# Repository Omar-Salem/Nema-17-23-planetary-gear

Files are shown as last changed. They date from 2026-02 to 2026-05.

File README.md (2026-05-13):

# Nema-17/23-planetary-gear

A fully parametric planetary gearbox designed for NEMA 17/23 motors.

Gear ratio, backlash, and geometry can be adjusted through parameters.

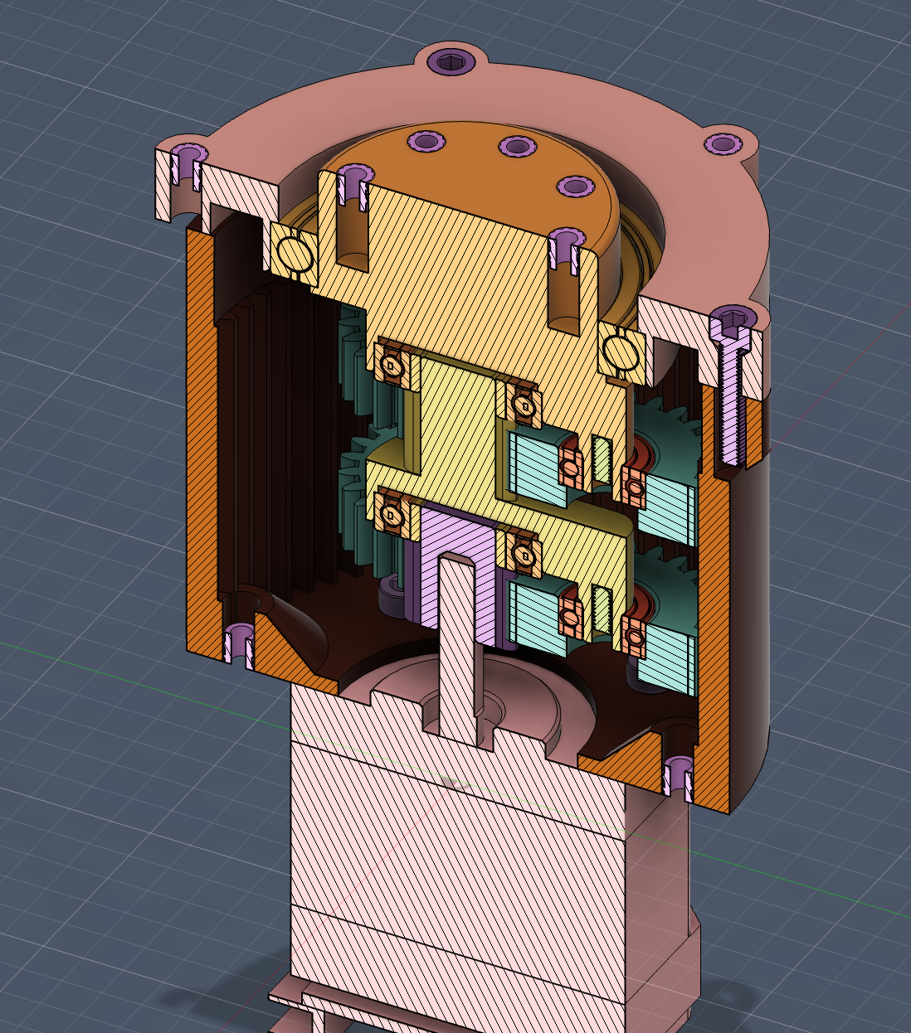
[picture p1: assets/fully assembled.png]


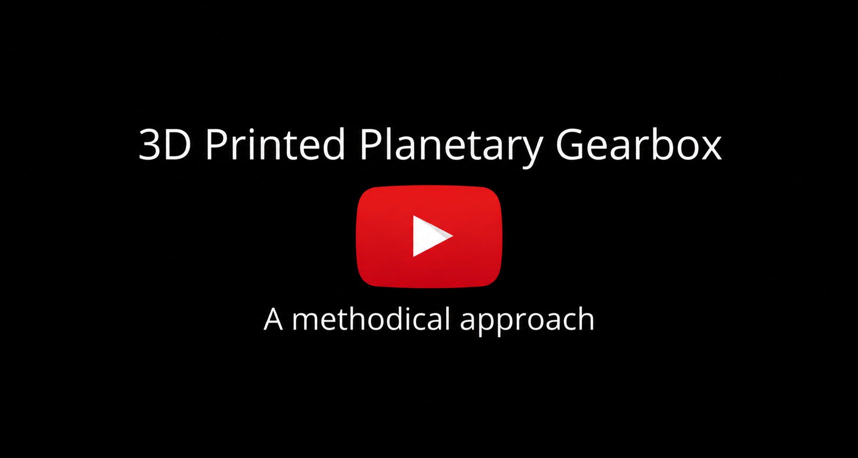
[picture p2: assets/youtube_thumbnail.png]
Watch the video (https://www.youtube.com/watch?v=zlH5y5JG1OU)


### Software Requirements 
[Fusion 360 (free to download)](https://www.autodesk.com/campaigns/fusion-360/download)

[Fusion 360 Helical Gear Plus plugin](https://apps.autodesk.com/FUSION/en/Detail/Index?id=1259509007239787473&appLang=en&os=Mac)

### Parts List
#### for Nema 17
* M3 heat inserts 
    * (L5 $\times$ 4.2mm OD) $\times$ 15
* M3 hex bolts
    * 91290A120 (16mm)  $\times$ 3
    * 91290A115 (10mm)  $\times$ 6
    * 91290A111 (6mm)  $\times$ 4
* Deep groove ball bearings
    * 4668K269 (35mm $\times$ 47mm $\times$ 7mm) $\times$ 1
    * 2349K726 (12mm $\times$ 21mm $\times$ 5mm) $\times$ 2
    * 4668K225 (5mm $\times$ 11mm $\times$ 5mm) $\times$ 6
#### for Nema 23
Substitute `91290A111` M3 hex bolts with `91290A221` M5

The above is for `gear_ratio` **6**, for different ratios you'll need different bearing sizes, refers to parameters in design files
### Design Notes

* Spur gears are used for simplicity and efficiency
* Sun gear is reused across configurations
* Three planets provide a balance between load sharing and complexity
* Geometry is driven by parameters (module, teeth count, bearing sizes)
* Single sided carrier

### Important Limitation
Parameters are not global across files.

If you change a parameter (e.g. `gear_ratio`, `helix_angle` etc..), you must update it in all other files.

This violates DRY principle, instead, global params should be used.

[Global Parameters in Fusion 360 | Explained in 5 minutes](https://www.youtube.com/watch?v=VsqRV7JvBKc)

### Workflow Overview
The gearbox is built in three stages:

* Generate base gears (sun, planet, ring)
* Modify components 
* Assemble stages 

### Generate Gears

Create a new project and import the .f3d files

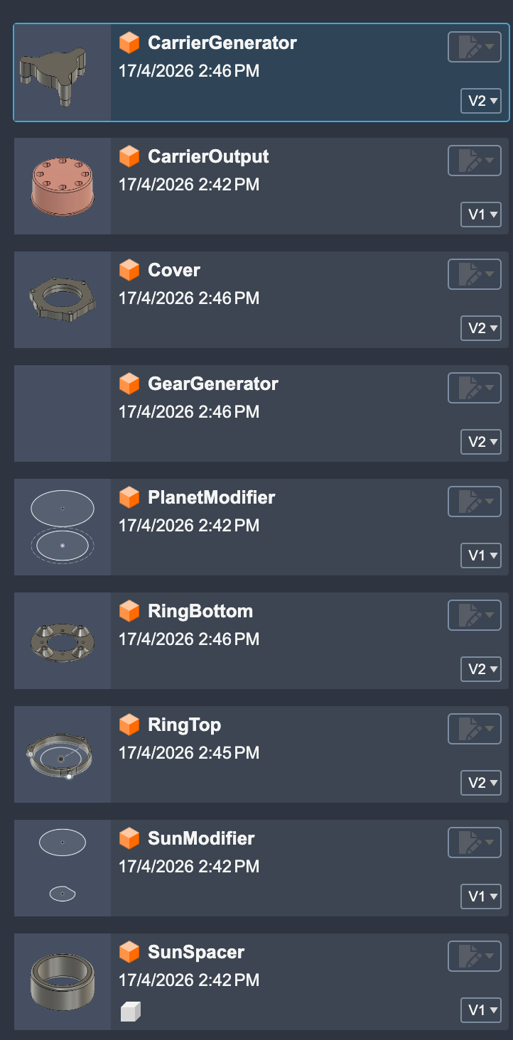
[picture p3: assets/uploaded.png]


Open `GearGenerator`

Start creating the sun gear, open `Helical Gear+`

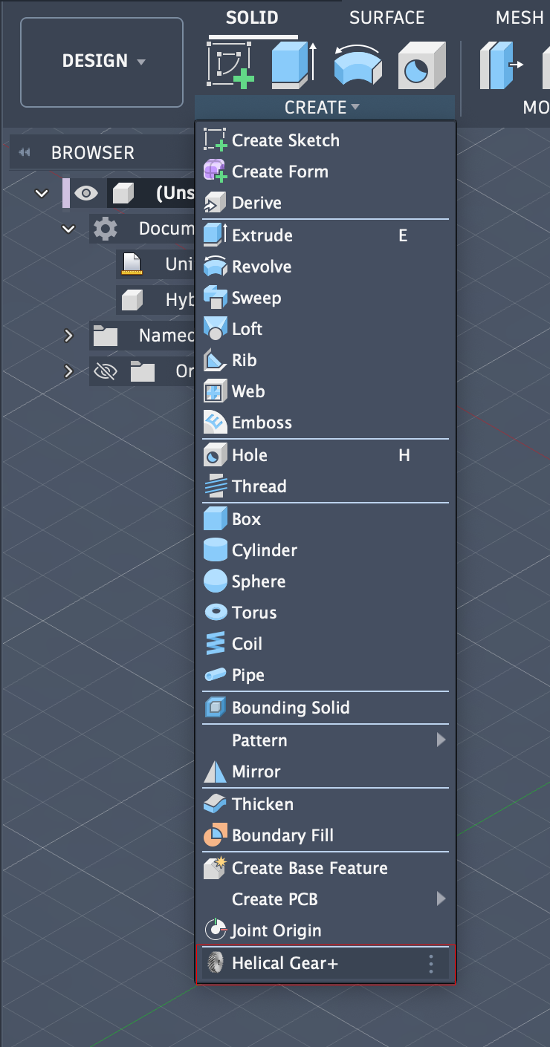
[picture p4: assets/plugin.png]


Fill the fields with the sun gear params

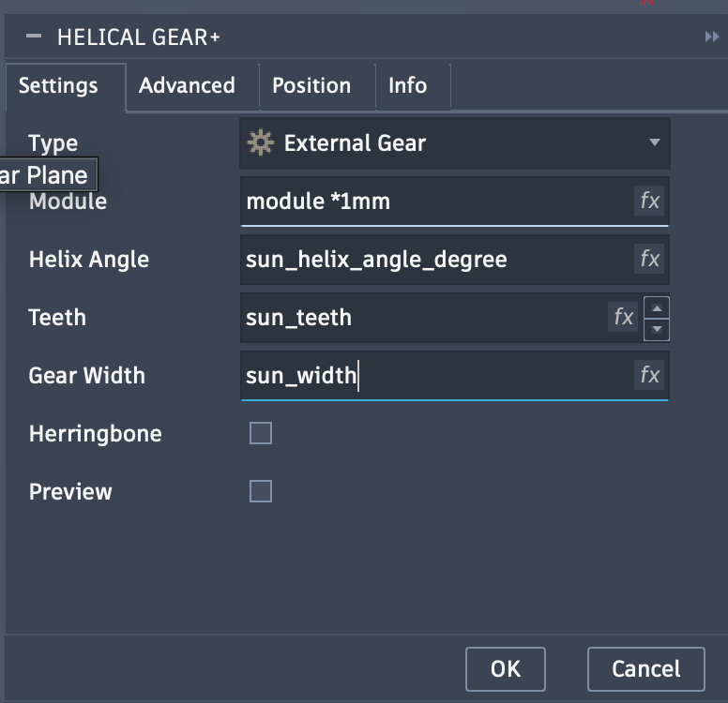
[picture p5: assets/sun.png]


(_Advanced config will be the same for planet and ring_)

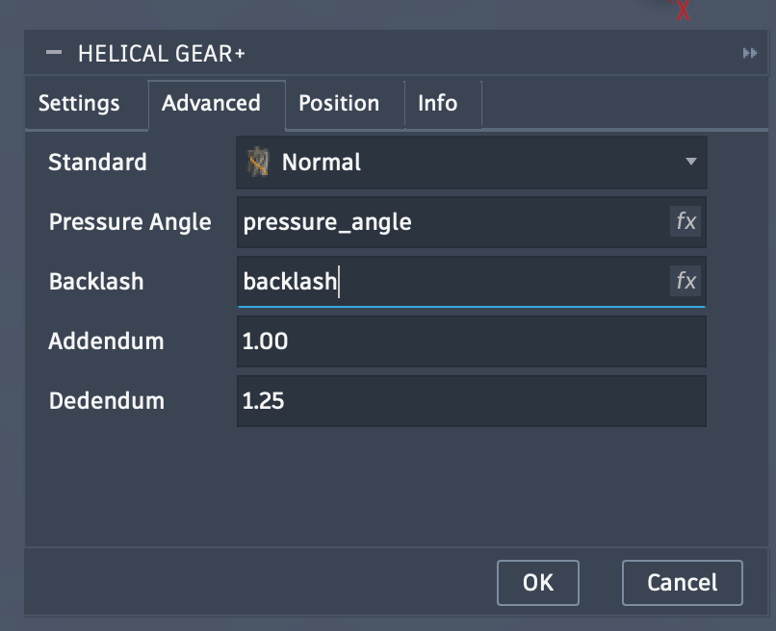
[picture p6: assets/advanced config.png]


In the same manner create the planet gear

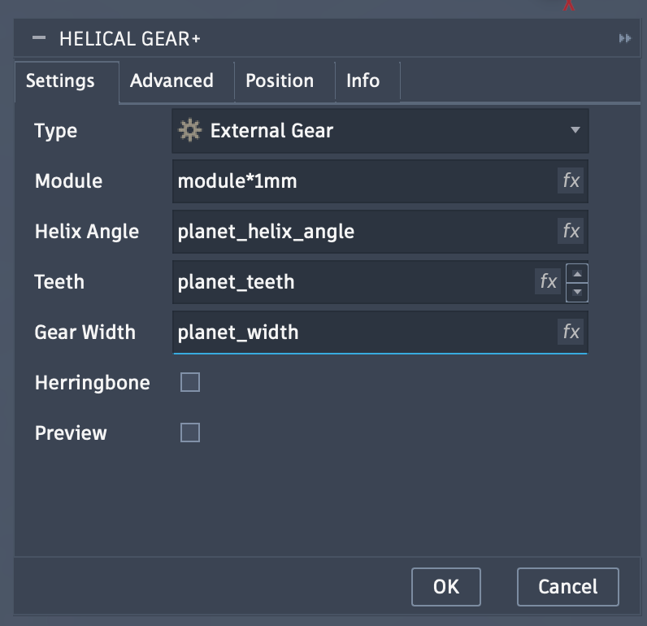
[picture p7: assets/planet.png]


And the ring gear, don't forget to change Type to `Internal Gear`

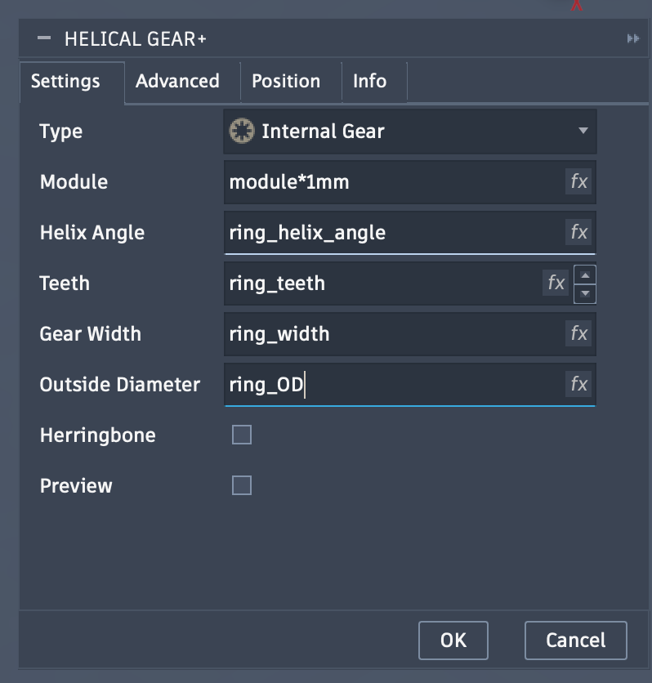
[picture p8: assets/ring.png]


You should end up with this

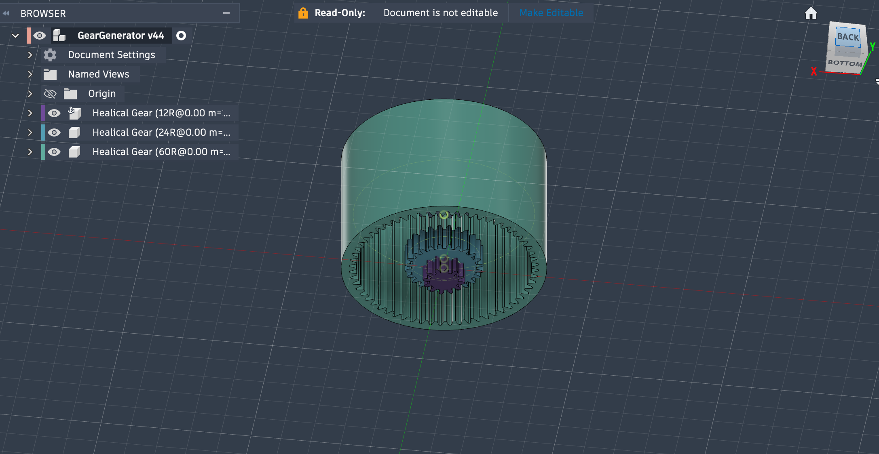
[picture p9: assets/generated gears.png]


Export ring gear as `Ring` to your project

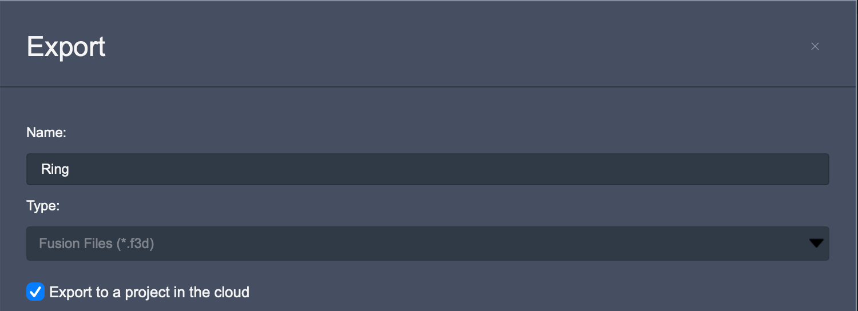
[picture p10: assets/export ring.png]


Export planet gear as `PlanetTemp` and sun gear as `SunTemp`

Close current design without saving

### Modify Components

Open `SunModifier`

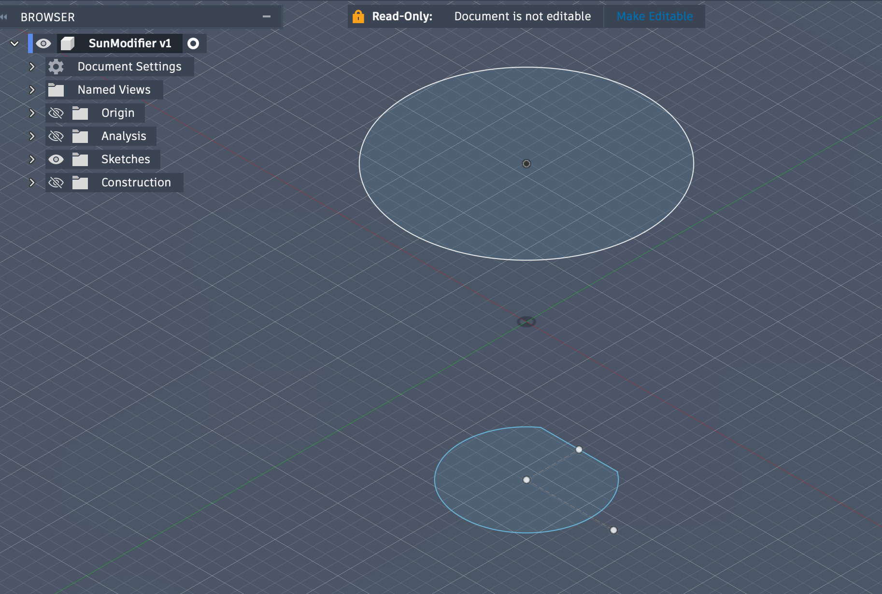
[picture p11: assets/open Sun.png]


Insert the `SunTemp` component

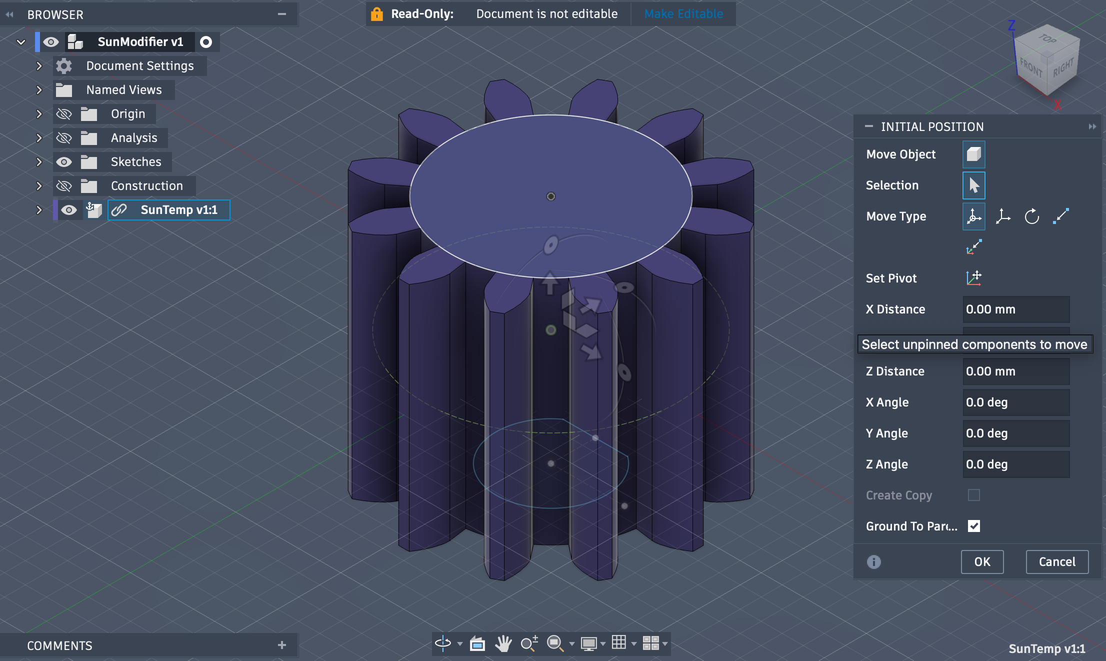
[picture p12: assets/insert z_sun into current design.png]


Break the link

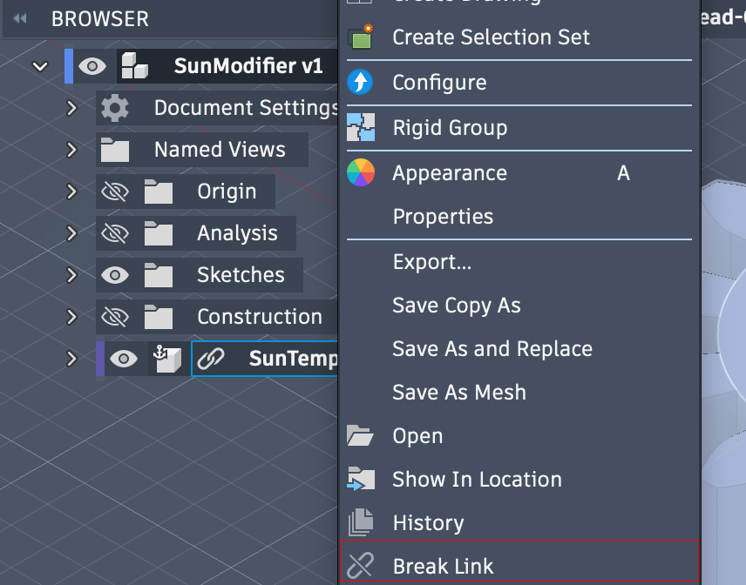
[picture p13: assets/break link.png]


Extrude and fillet the bearing mount, make sure operation for extrude is `Join`

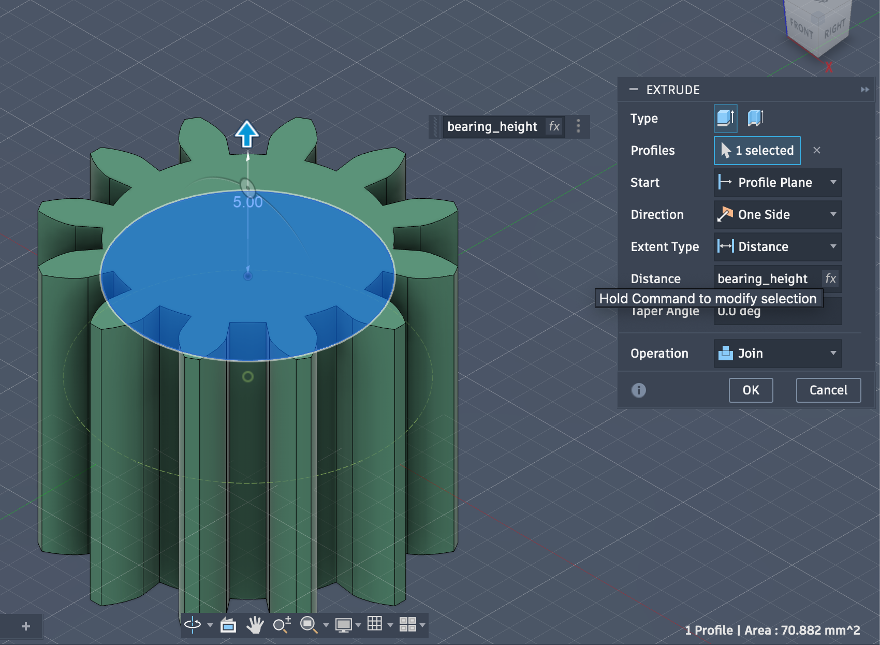
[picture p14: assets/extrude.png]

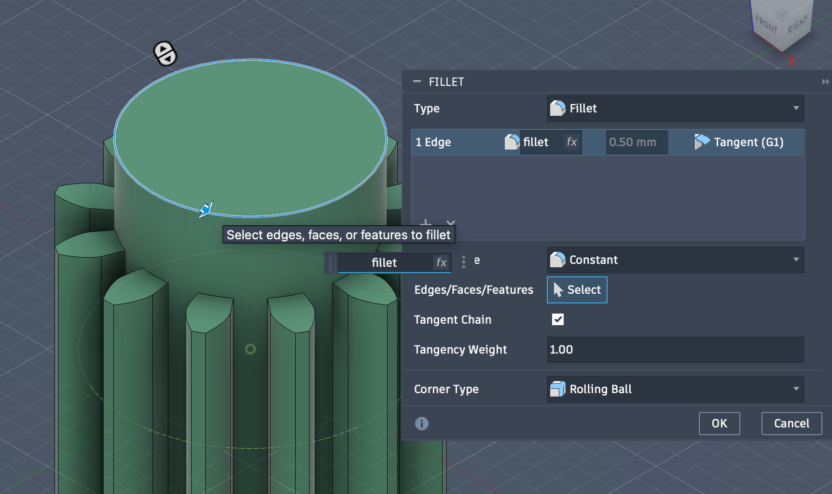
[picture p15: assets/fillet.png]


Export component as `Sun` to your project

Cut and fillet motor shaft

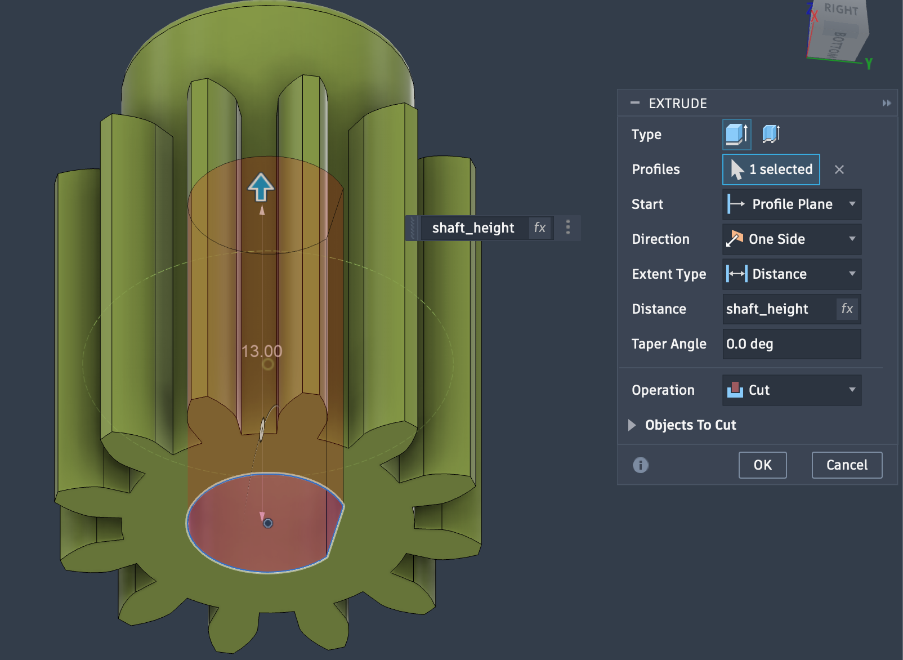
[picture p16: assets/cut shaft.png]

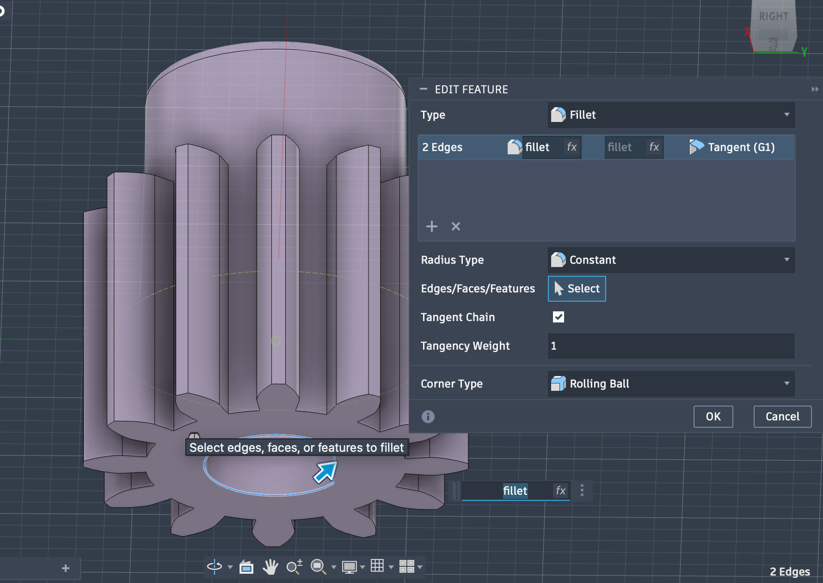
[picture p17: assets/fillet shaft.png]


Chamfer from the inside

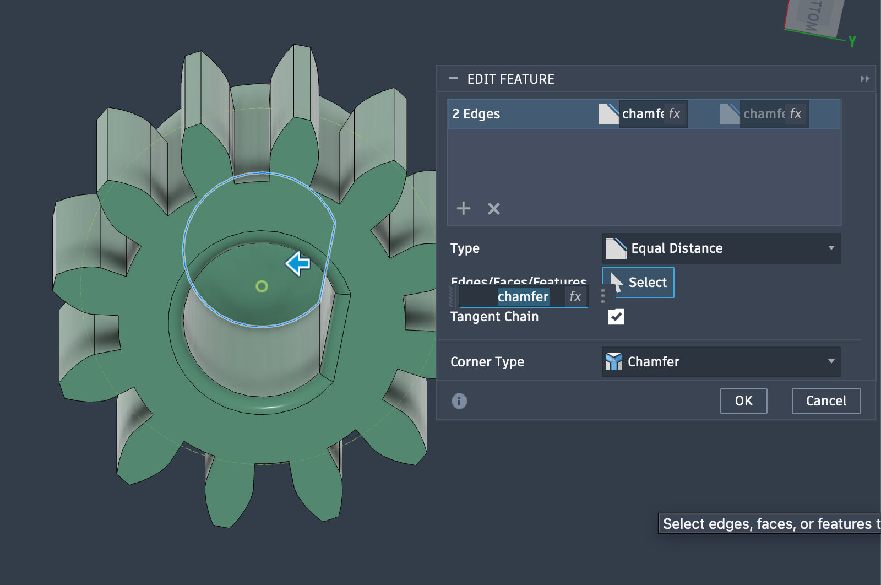
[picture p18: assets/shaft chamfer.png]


Should end up with this

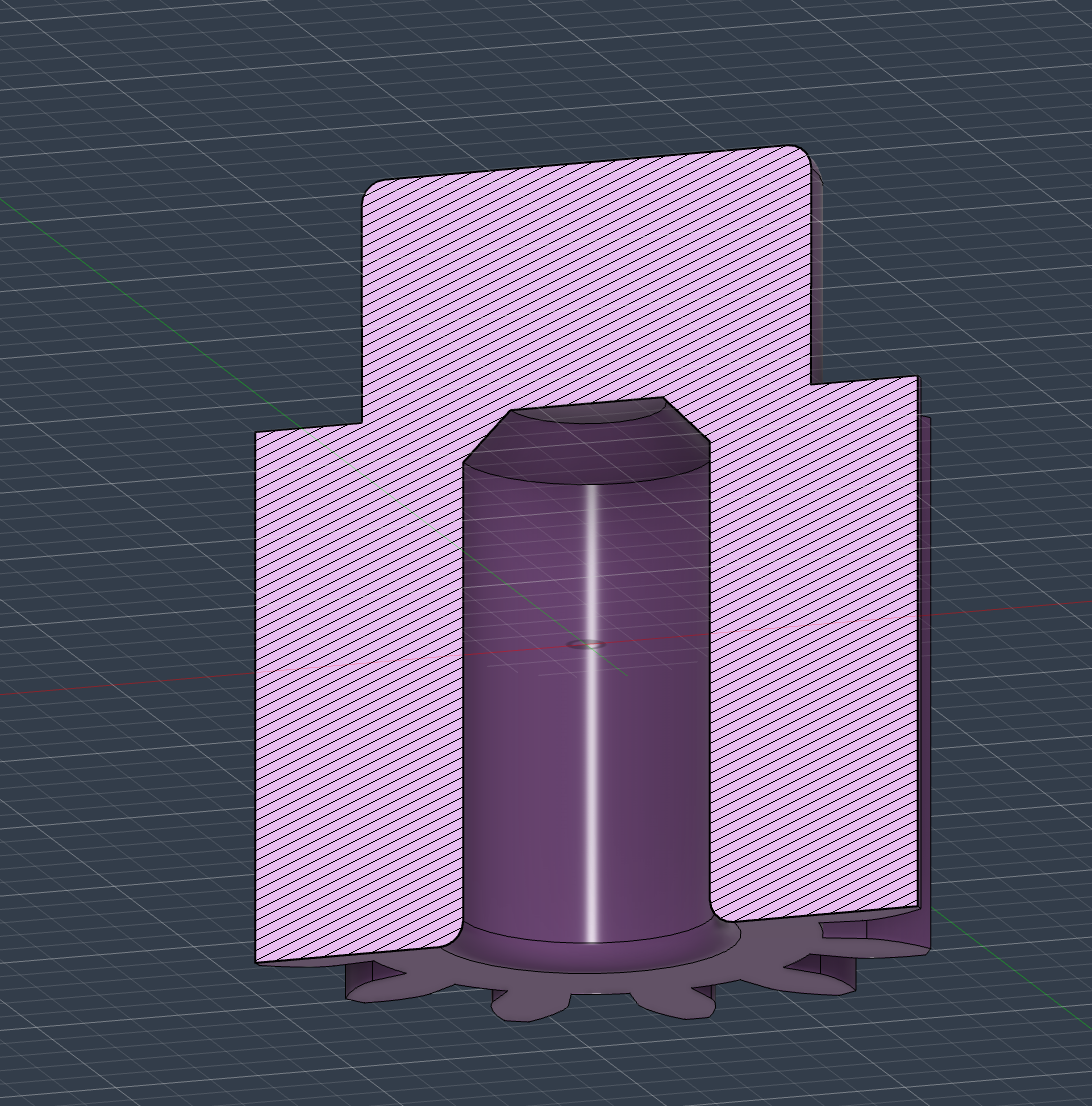
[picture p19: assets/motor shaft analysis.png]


Export component to project as `MotorInput`

Close current design without saving

_If you create another gearbox with a different gear ratio, `Sun` and `MotorInput` will stay the same, no need to regenerate them_

Move `SunTemp` to trash

---
In the same manner, open `PlanetModifier` and insert `PlanetTemp`

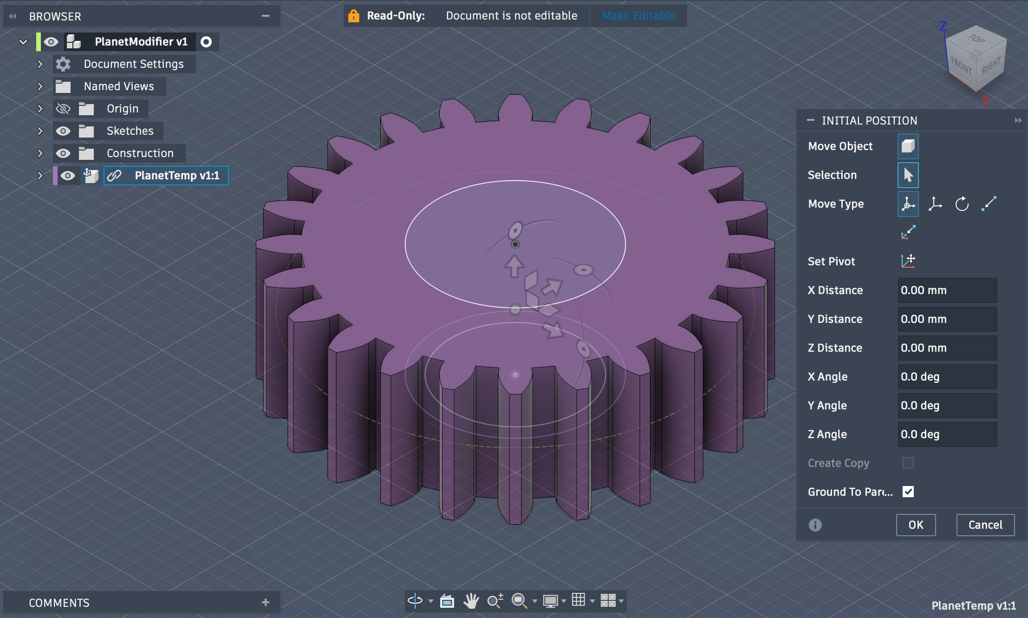
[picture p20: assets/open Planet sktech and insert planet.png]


Break link

Cut hole for bearing

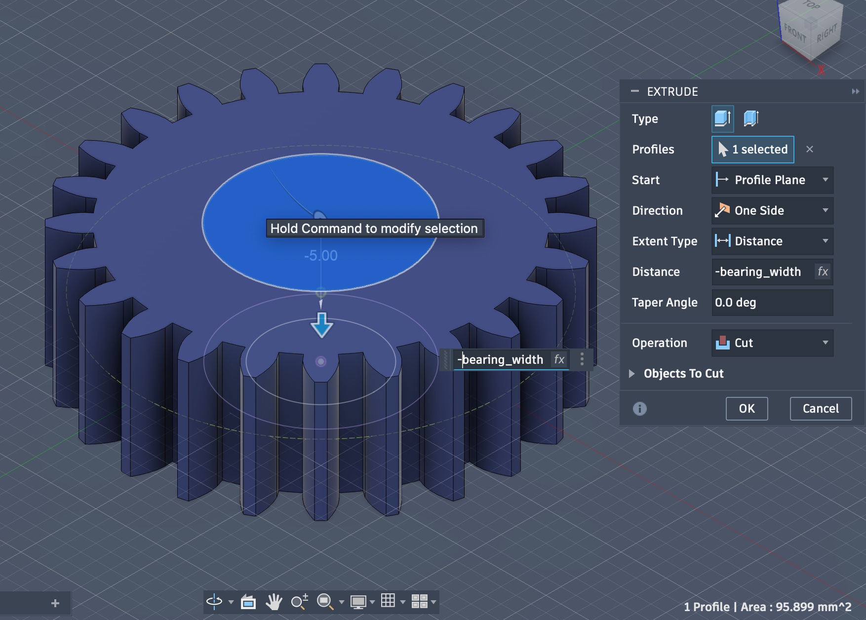
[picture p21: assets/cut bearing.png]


Fillet

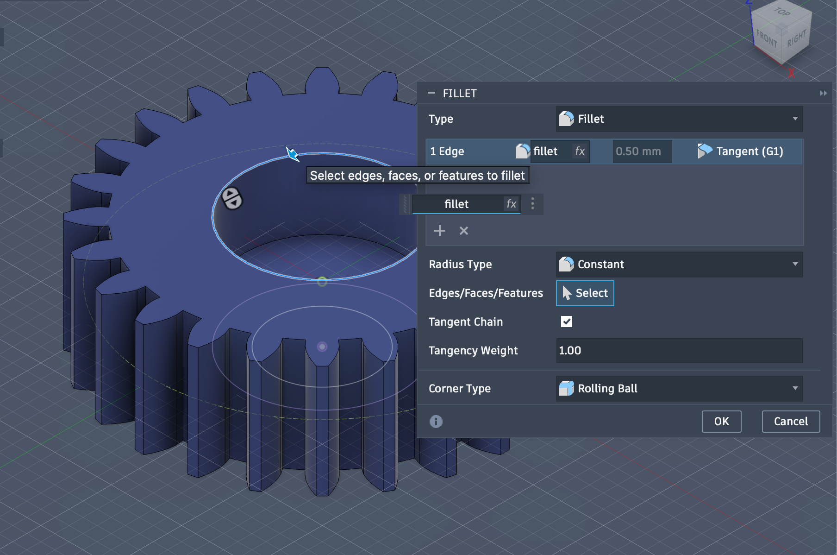
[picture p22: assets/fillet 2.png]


Cut hole for bearing lip

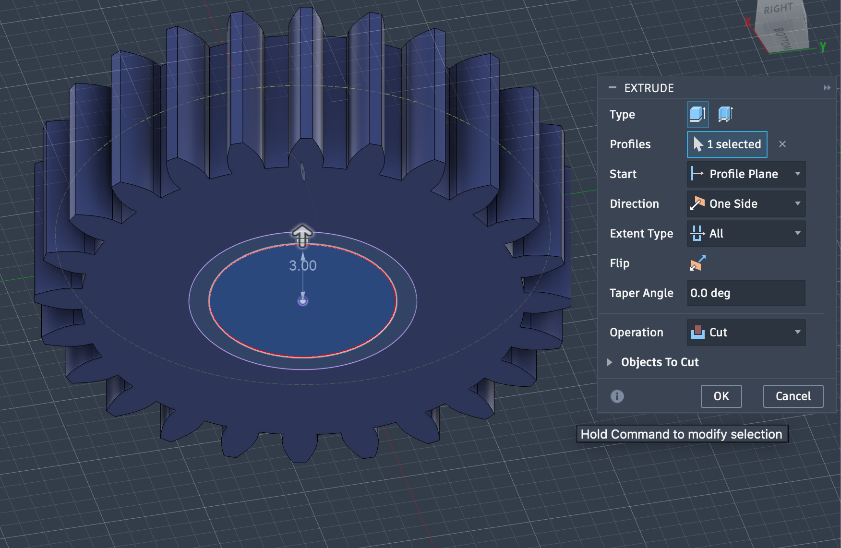
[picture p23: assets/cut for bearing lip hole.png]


Should end up with this

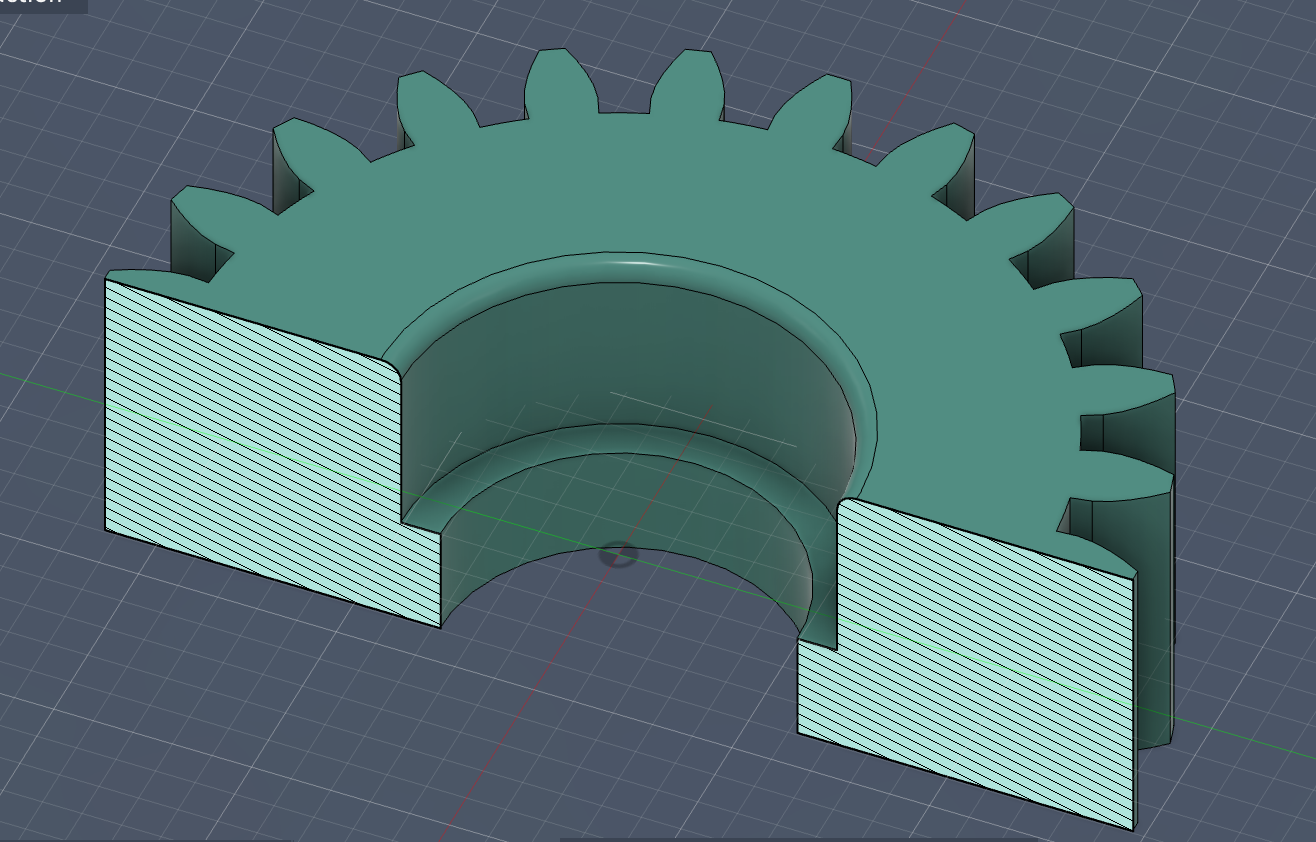
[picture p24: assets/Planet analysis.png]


Export to project as `Planet`

Close current design without saving

Move `PlanetTemp` to trash

We now have all the components, time to combine them

### Assemble Components

Open `Ring`, import `RingBottom` and `RingTop`

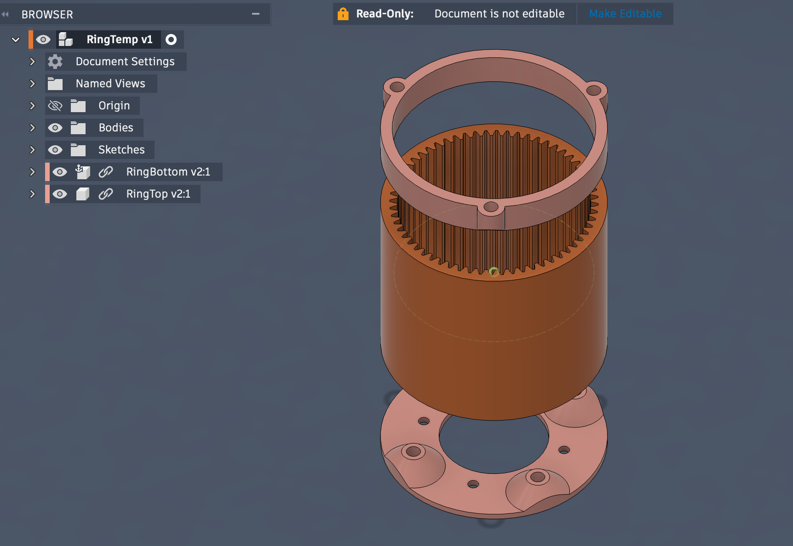
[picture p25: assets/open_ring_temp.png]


Join `RingBottom` and `Ring` at their bottoms

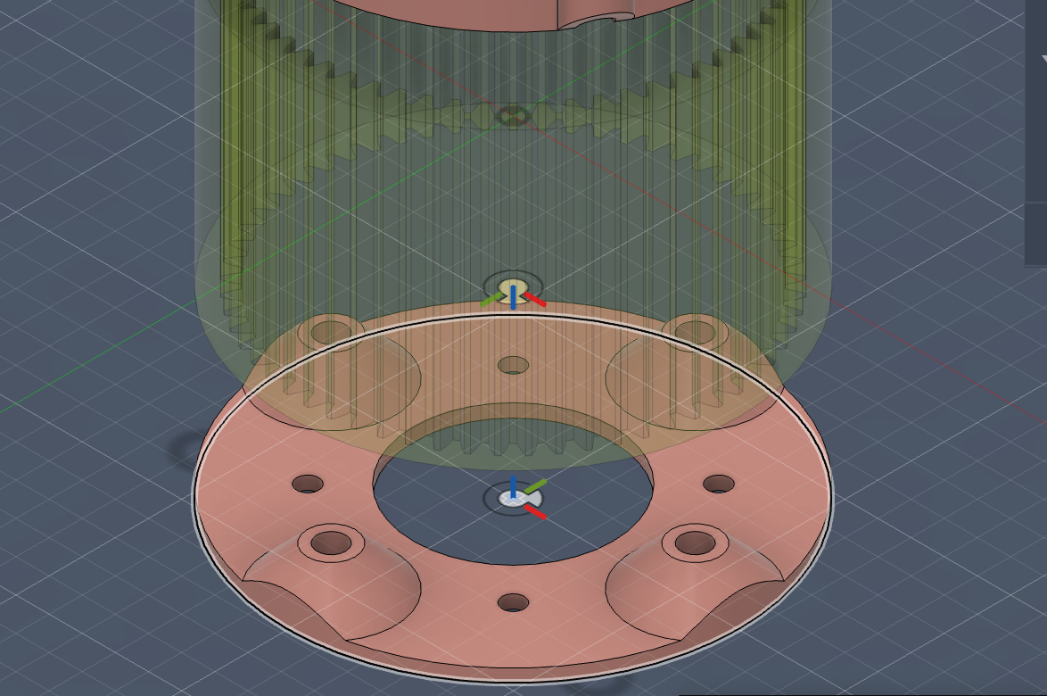
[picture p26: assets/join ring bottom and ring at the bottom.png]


Join `Ring` and `RingTop` at their tops

Should end up with this

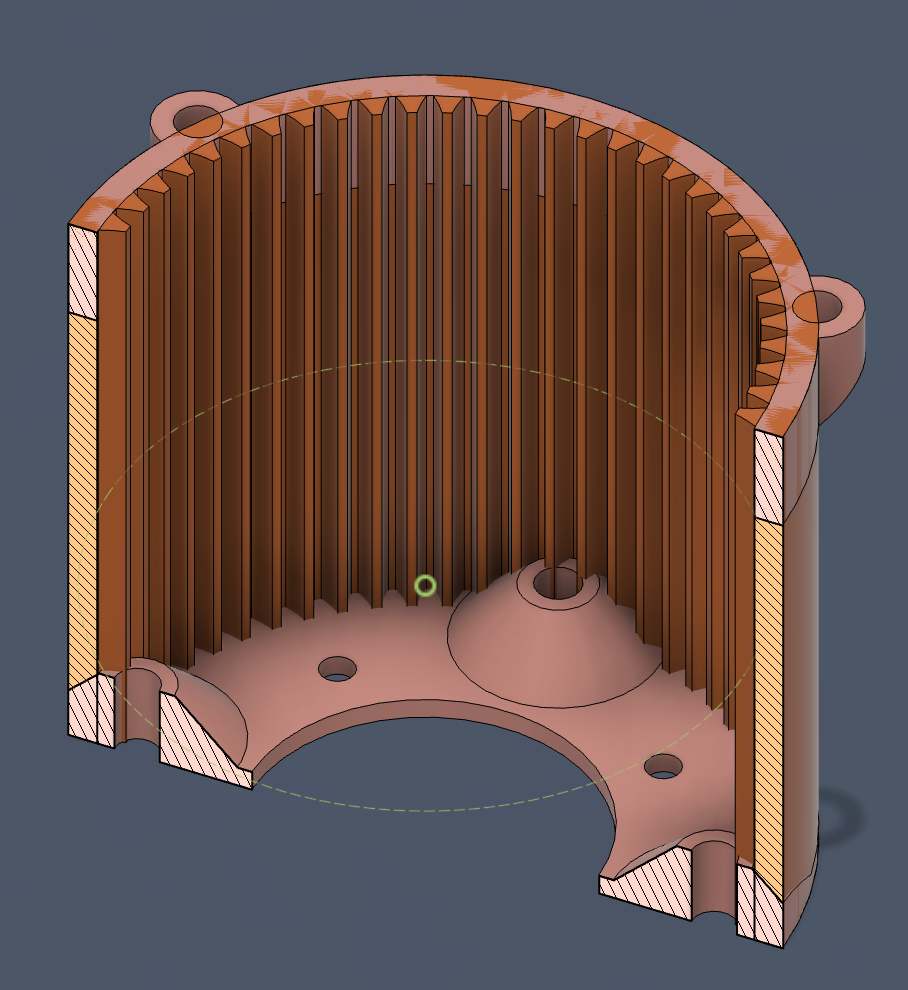
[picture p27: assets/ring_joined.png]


Combine all of them

Select and cut the 3 screw mounts

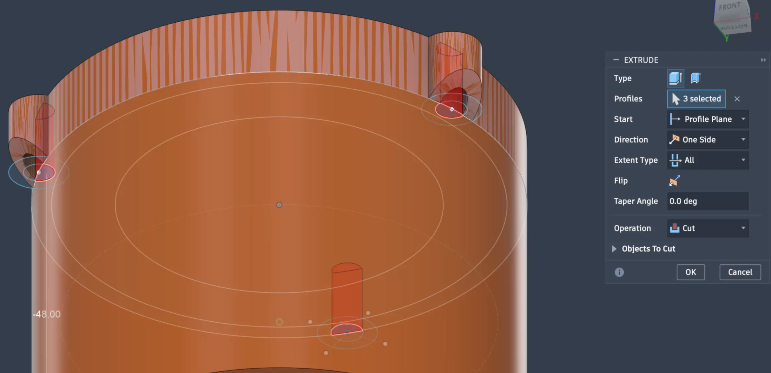
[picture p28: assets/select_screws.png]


Remove `RingBottom` and `RingTop`

Save

---

Open `CarrierGenerator`

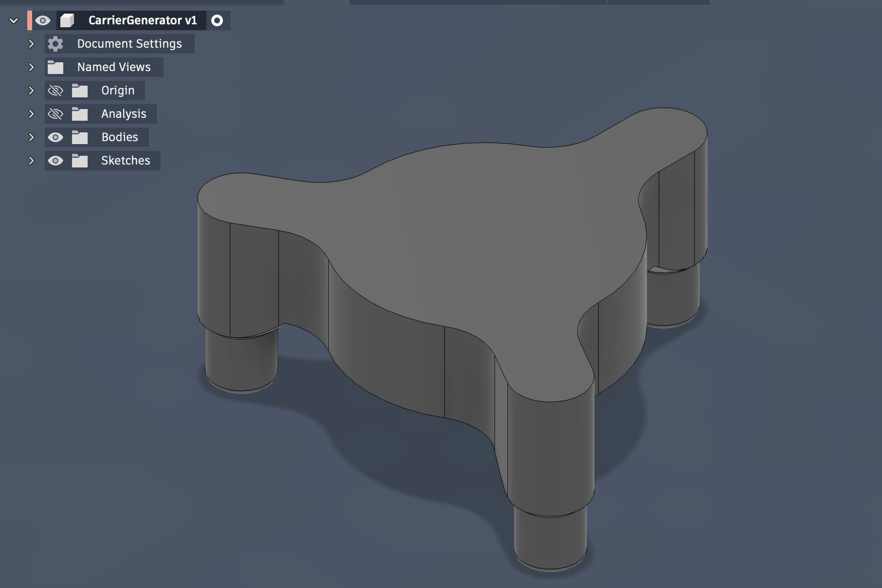
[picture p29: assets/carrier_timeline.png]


Insert `Sun`

Join `Sun`'s bottom with `Carrier`'s top at their centers

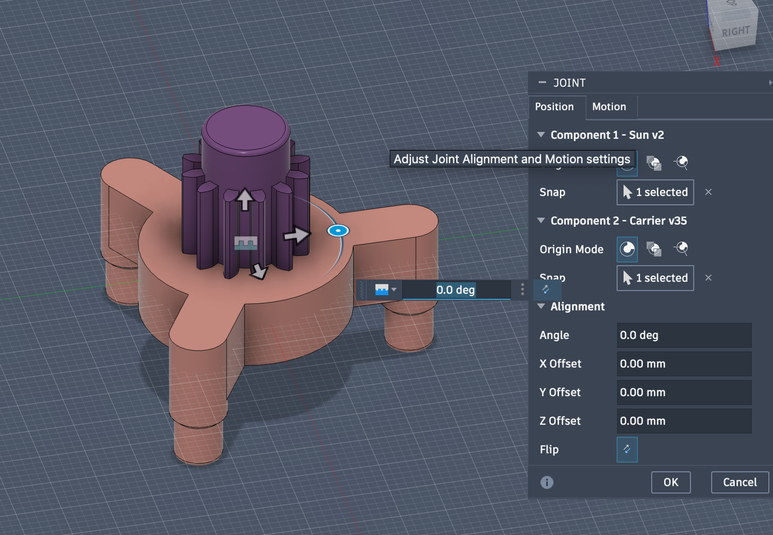
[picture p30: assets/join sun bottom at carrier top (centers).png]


Should end up with this

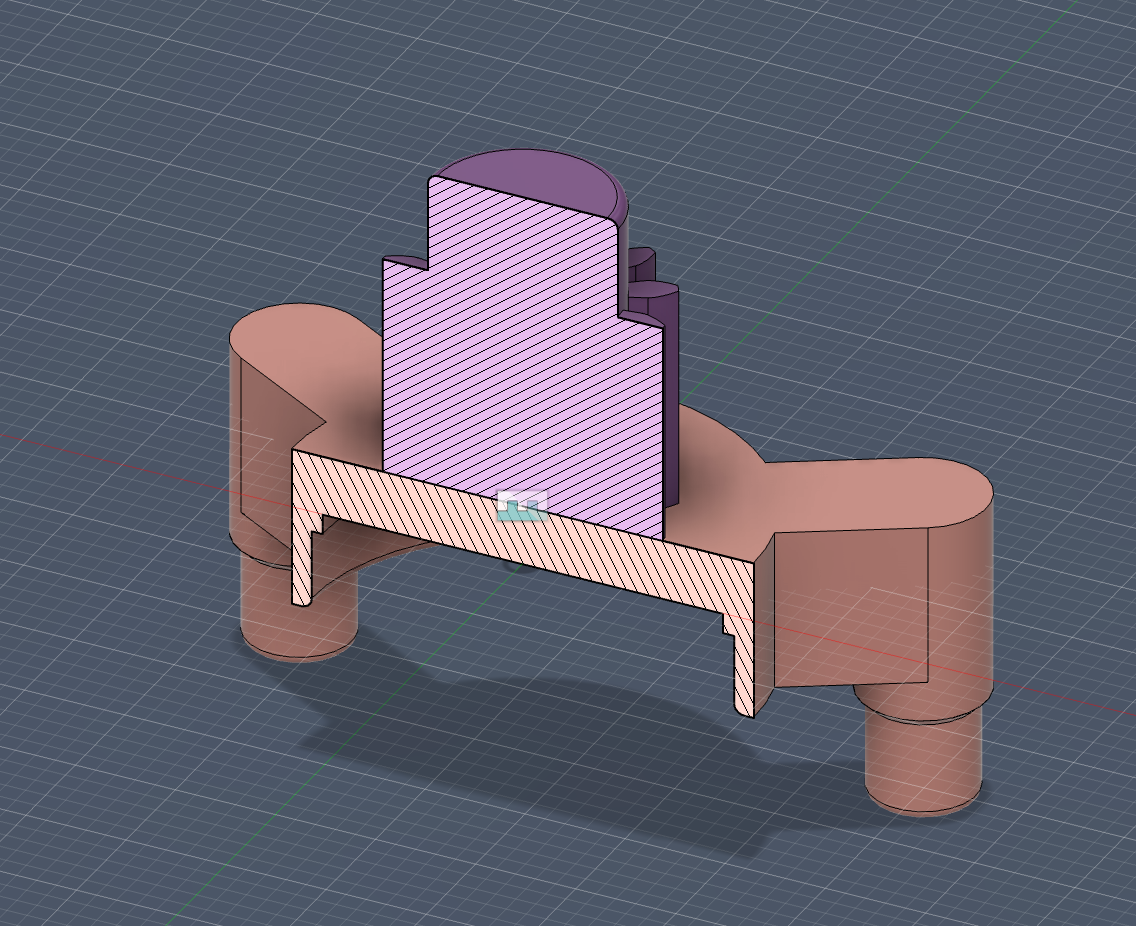
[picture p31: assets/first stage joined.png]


Combine all of them as new component

Export it to project as `FirstStage`

Close current design without saving

---

Open `CarrierGenerator` again

Insert `CarrierOutput`

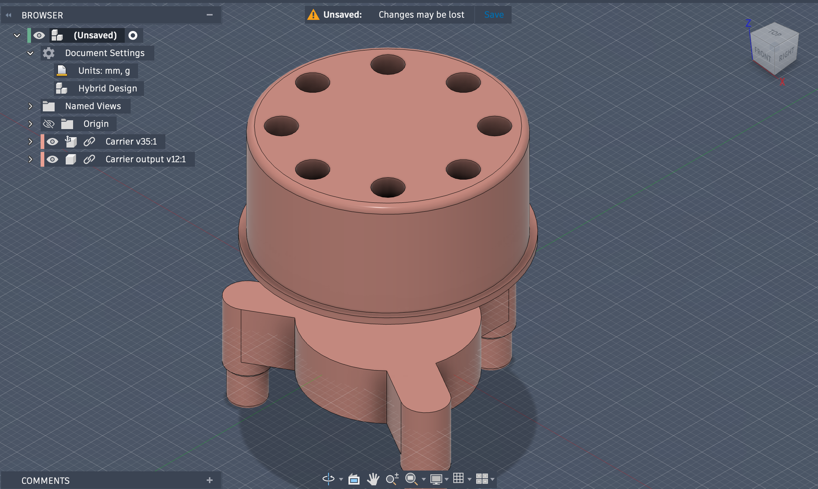
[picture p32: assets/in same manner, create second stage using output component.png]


Join `CarrierOutput` bottom at `CarrierGenerator`'s top at their centers

Should end up with this

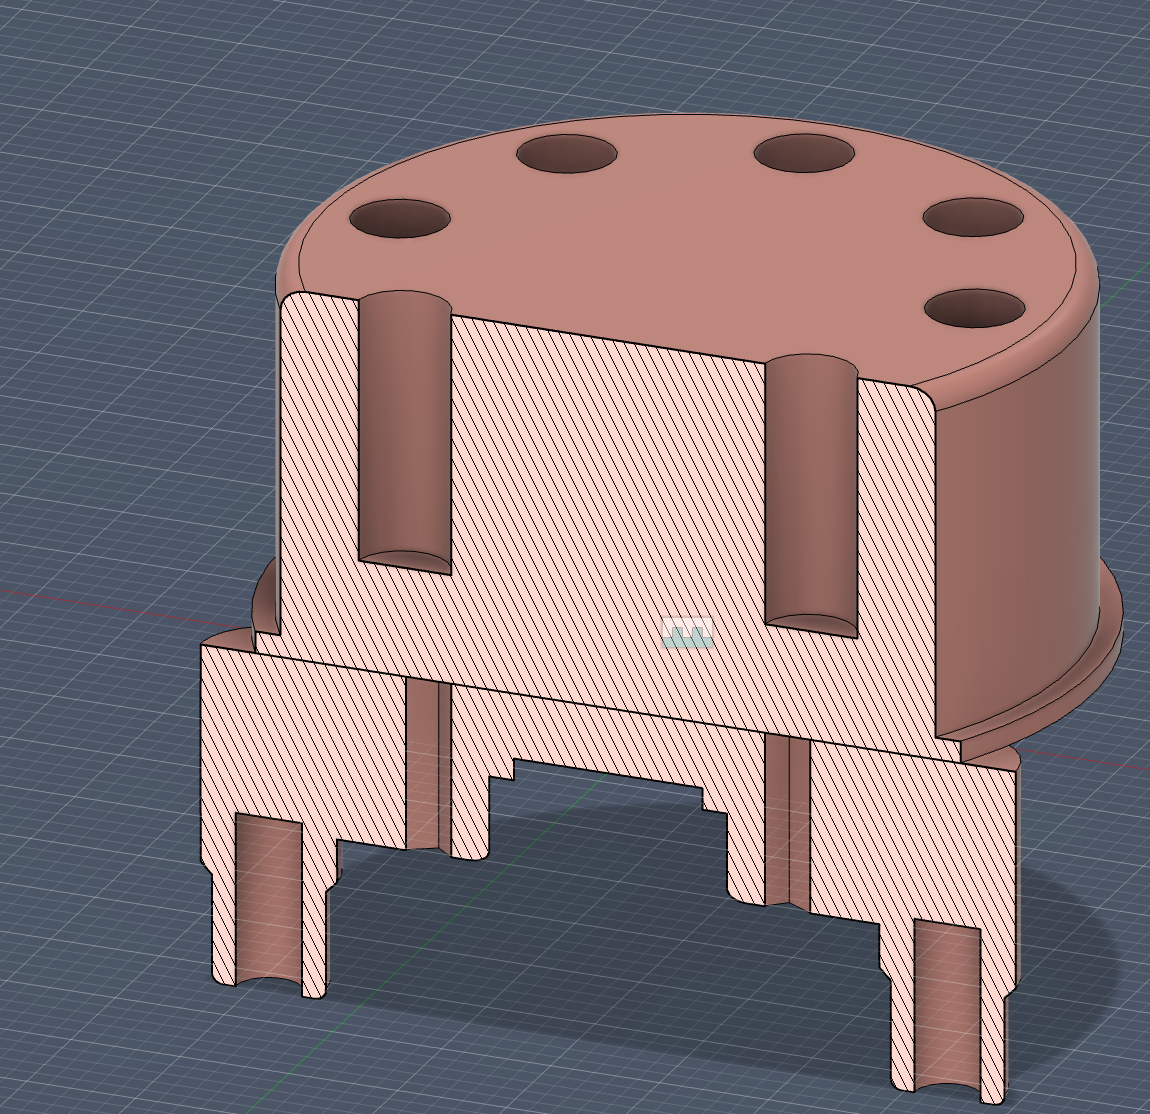
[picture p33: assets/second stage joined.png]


Combine all as new component, export it to project as `SecondStage`

### Export for Printing

* Cover
* FirstStage
* SecondStage
* Ring
* Planet
* MotorInput
* SunSpacer

❗ Make sure you print `SecondStage` at 45&deg; with 100% infill as it takes the most stress

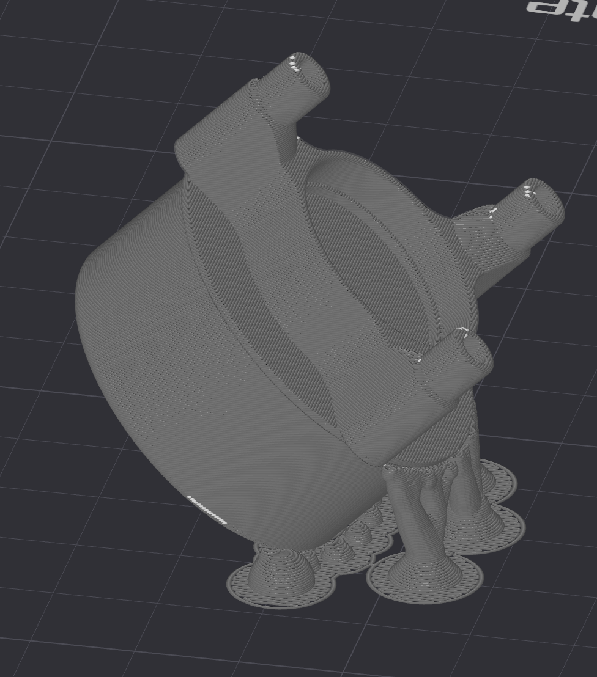
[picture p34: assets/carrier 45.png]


[The Correct Orientation to Print Boxes](https://www.youtube.com/watch?v=8NKVNwVaZU0)

[Autodesk Fusion: Make supports like Slant 3D](https://www.youtube.com/watch?v=sn2u949g7dM)

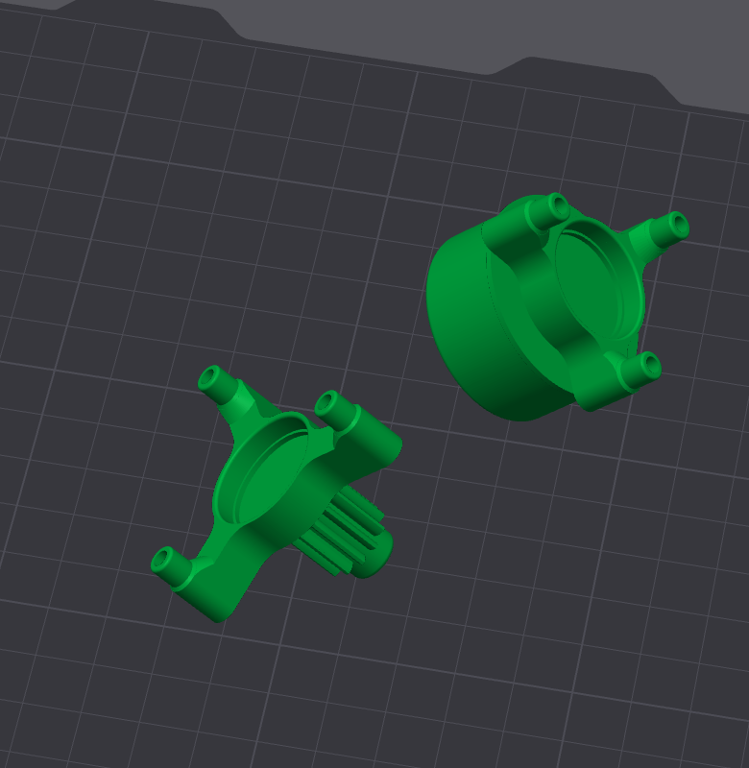
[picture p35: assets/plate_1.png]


6 `Planet`s

2 `SunSpacer`s (_1 per stage_)

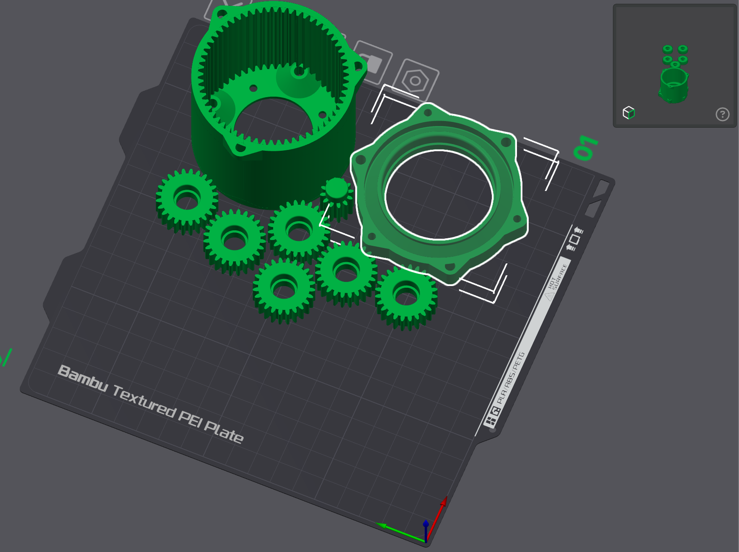
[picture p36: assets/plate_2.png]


### Assembly
1. Press the heat sinks into the ring.

1. Secure the sun gear onto the motor shaft. 

1. Bolt the ring to the motor using four 6mm M3 bolts. 

1. Seat the first 12mm bearing into the first stage, followed by the sun top to lock the sun in place. 

1. Install the three 5mm bearings onto the pins, mount the planet gears, and slide the first stage into position. 

1. Repeat these steps for the second stage, adding the three 10mm M3 bolt pin supports. 

1. Fit the 35mm bearing onto the output shaft.

1. Attach the cover with three 16mm M3 bolts.

1. Press the remaining heat sinks into the cover and output shaft.
 
 _Bearing sizes will change depending on gear ratio_

https://github.com/user-attachments/assets/527c2508-7acf-4f8b-a0d8-41f765740e9c

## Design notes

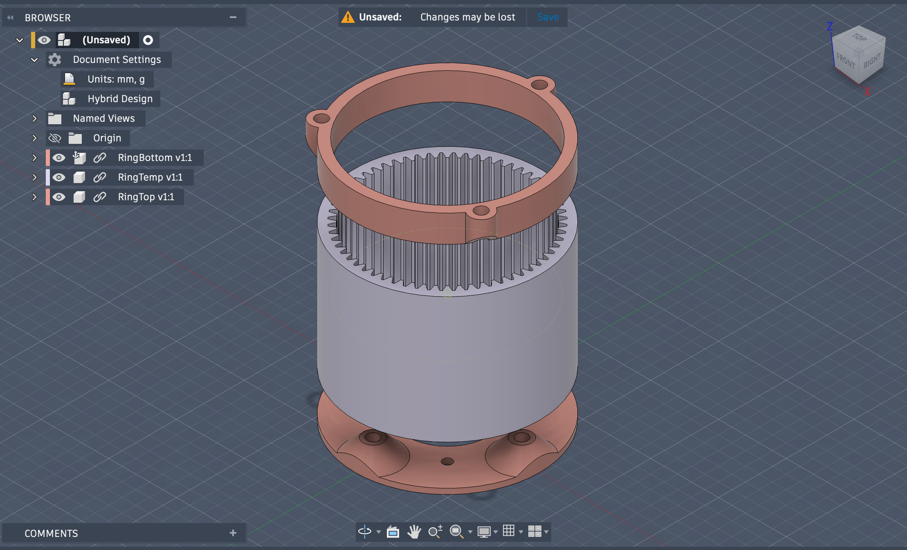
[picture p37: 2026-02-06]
assets/new hybrid design, insert ring,ring top and ring bottom.png

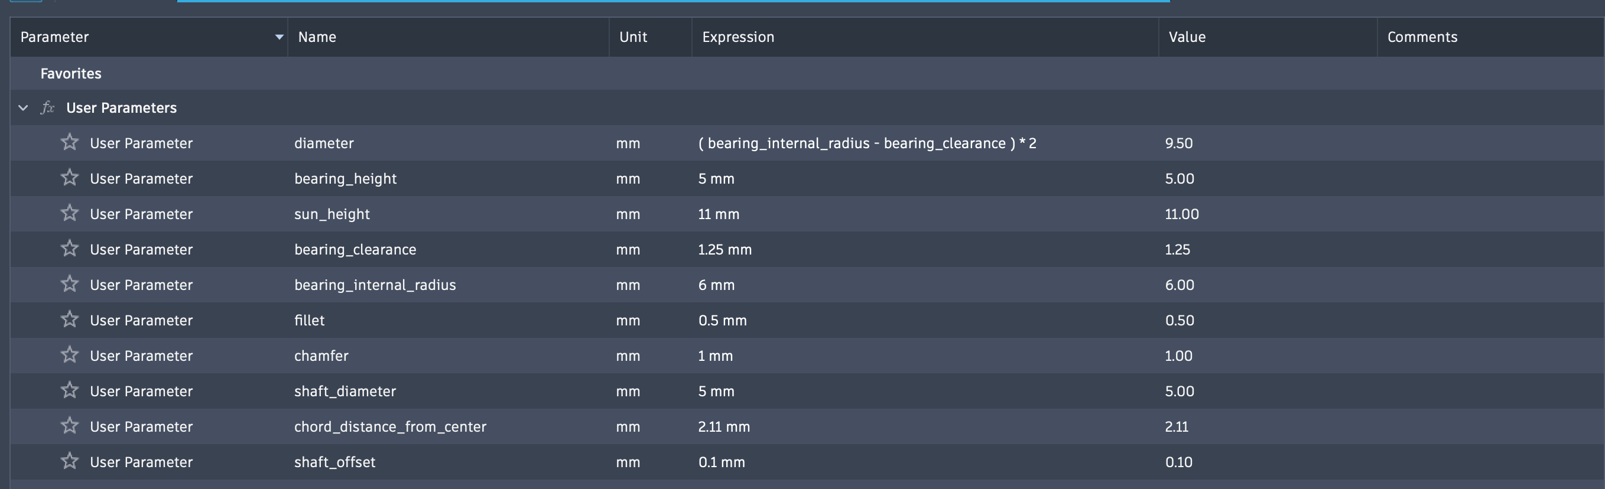
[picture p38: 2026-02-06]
assets/sun params.png

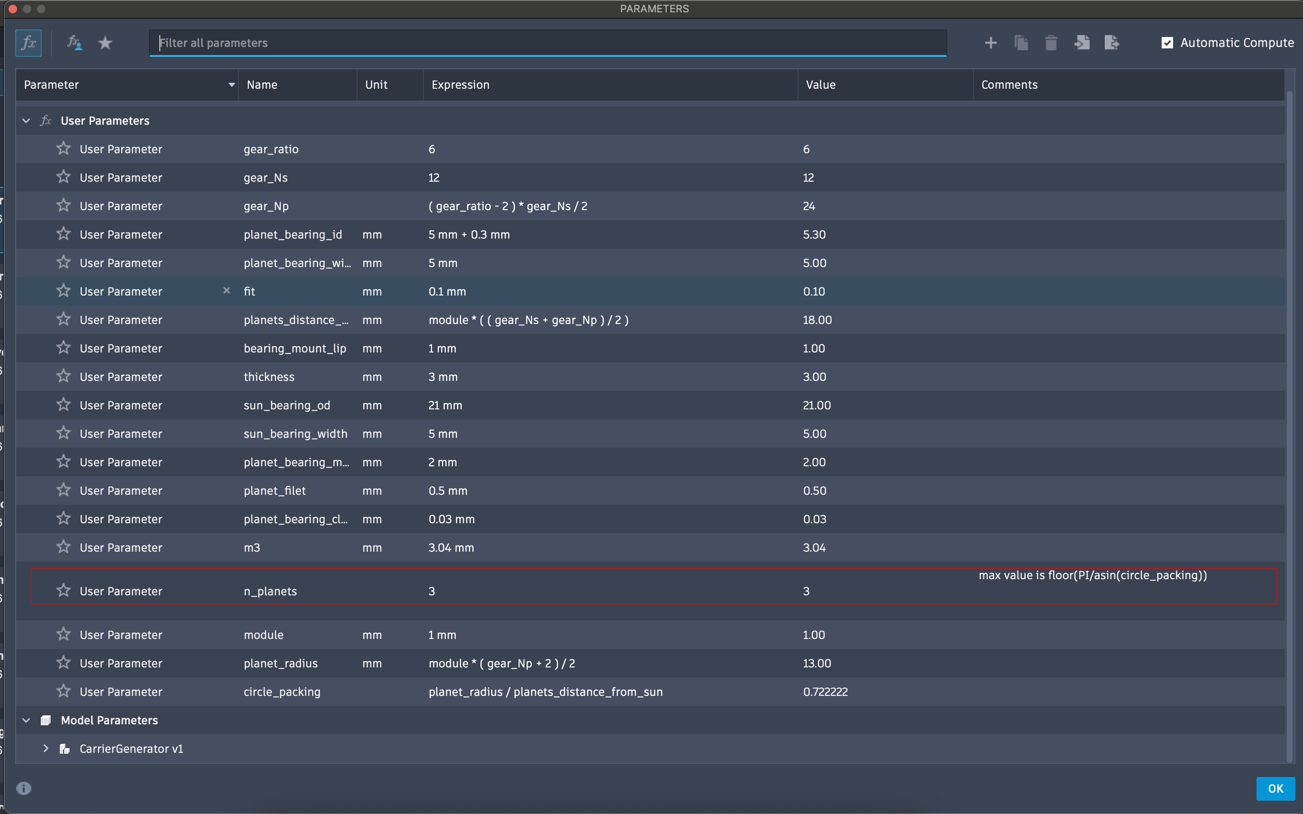
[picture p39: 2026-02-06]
assets/examine Carrier params.png

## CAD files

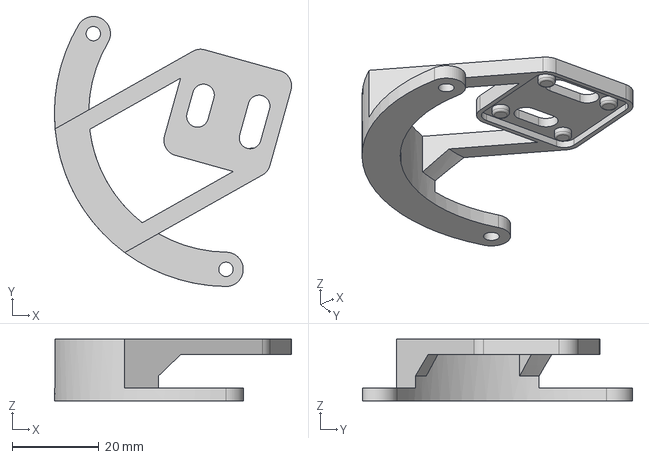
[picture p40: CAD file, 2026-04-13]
AS5600 mount.step
54.6 x 62.1 x 14.2 mm

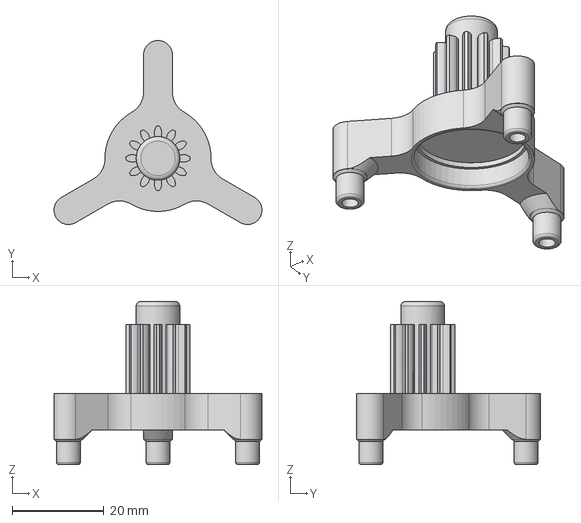
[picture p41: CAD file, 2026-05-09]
step files/Nema 17/6 to 1/FirstStage.step
45.3 x 40.0 x 35.5 mm

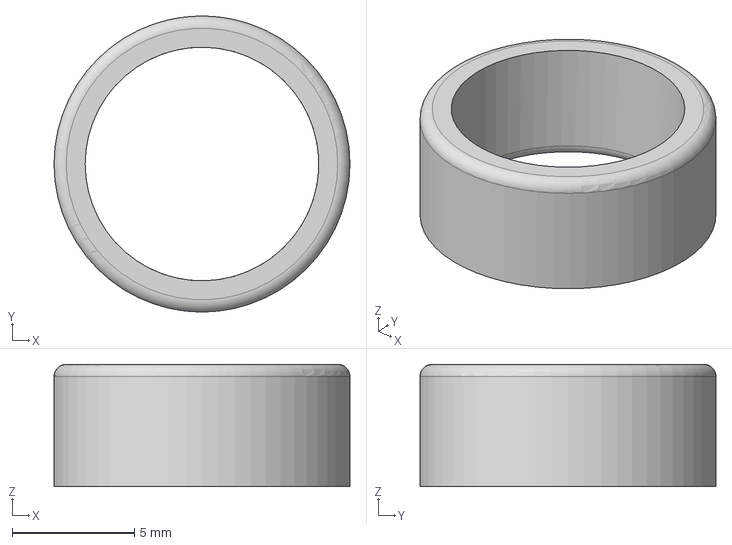
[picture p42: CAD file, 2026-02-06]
step files/SunTop.step
12.1 x 12.1 x 5.00 mm

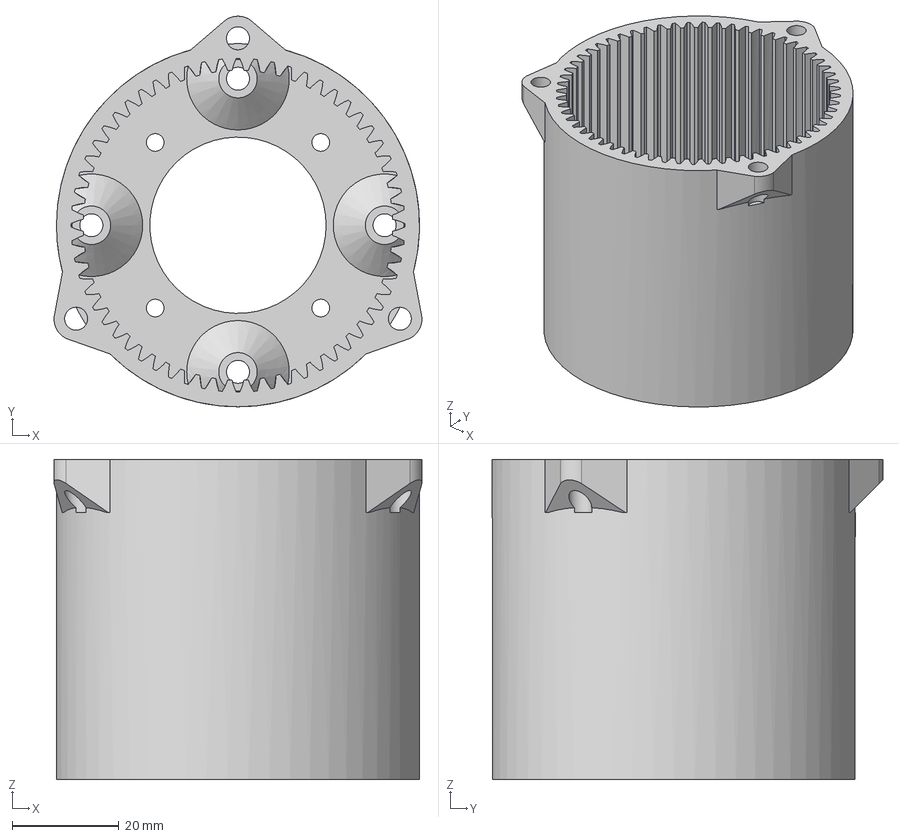
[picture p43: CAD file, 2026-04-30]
step files/Nema 17/6 to 1/Ring.step
68.9 x 73.2 x 60.0 mm

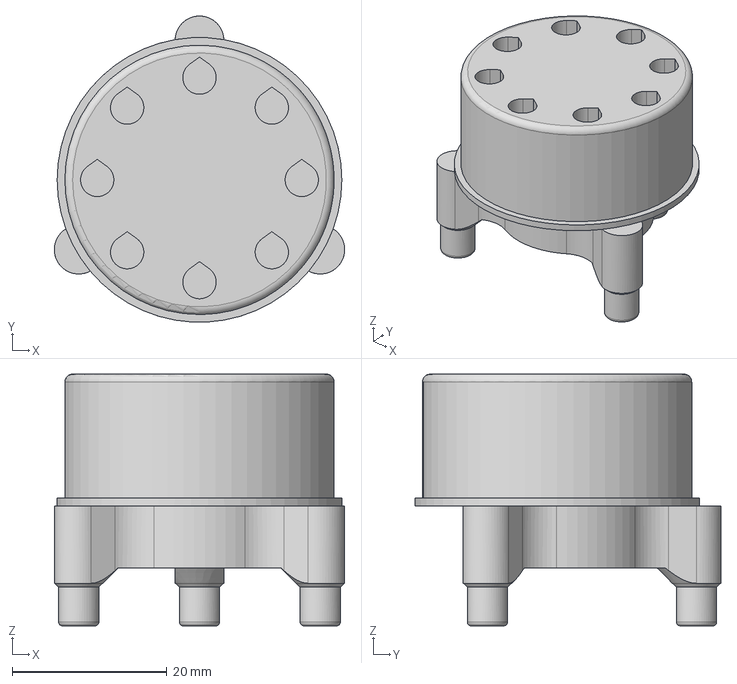
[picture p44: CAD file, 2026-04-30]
step files/Nema 17/6 to 1/SecondStage.step
37.5 x 39.5 x 32.5 mm

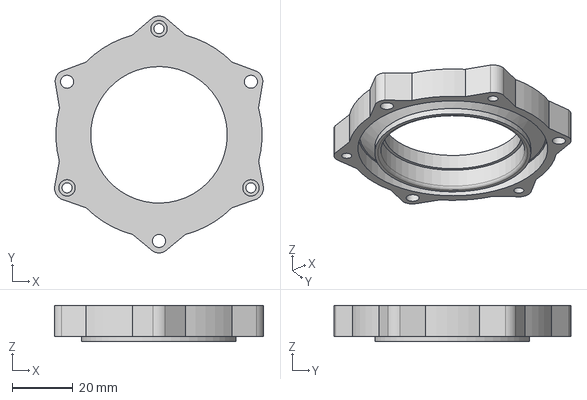
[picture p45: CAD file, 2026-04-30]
step files/Nema 17/6 to 1/Cover.step
68.9 x 78.1 x 12.0 mm

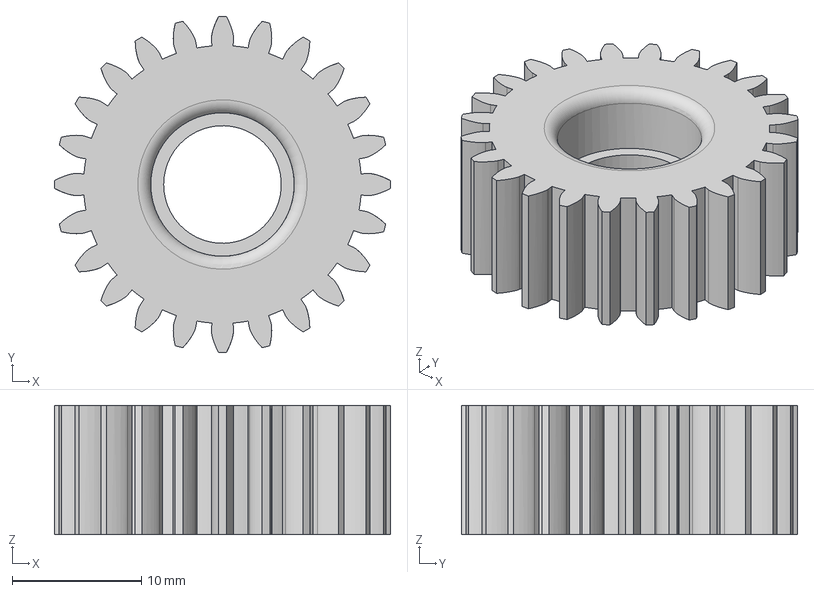
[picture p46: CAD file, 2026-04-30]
step files/Nema 17/6 to 1/Planet.step
26.0 x 26.0 x 10.0 mm

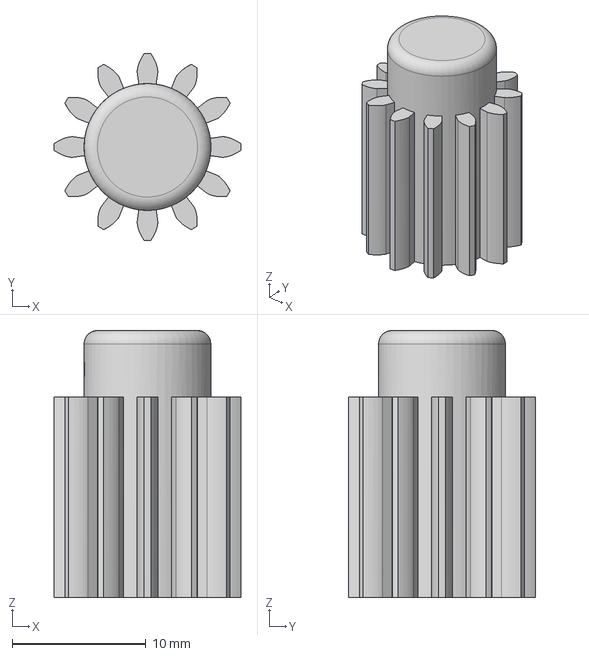
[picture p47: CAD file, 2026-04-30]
step files/Nema 17/6 to 1/MotorInput.step
14.0 x 14.0 x 20.0 mm

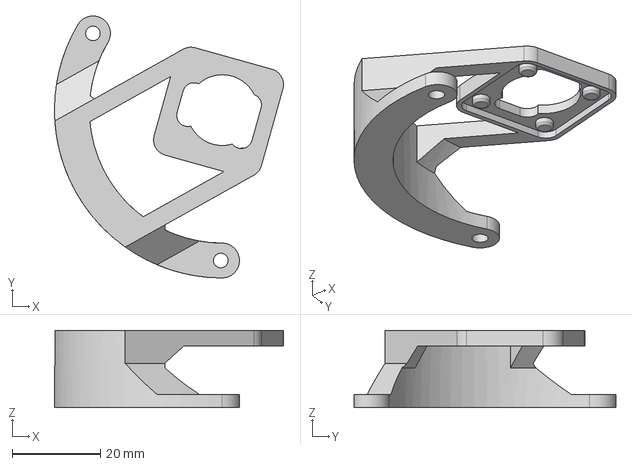
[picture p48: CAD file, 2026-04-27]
step files/Nema 17/6 to 1/AS5600 mount.step
51.8 x 59.2 x 17.5 mm

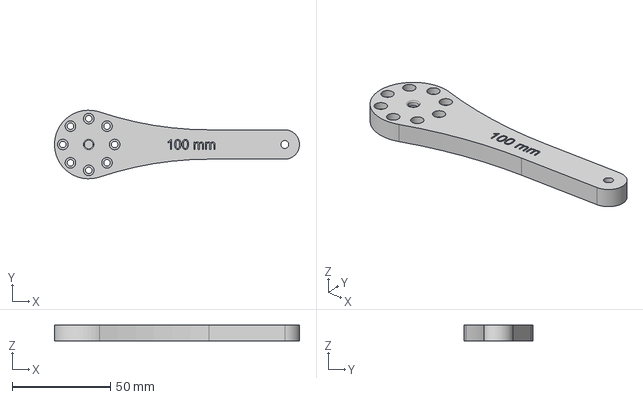
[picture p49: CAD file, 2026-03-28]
step files/Nema 17/6 to 1/lever.step
125.0 x 35.0 x 8.00 mm

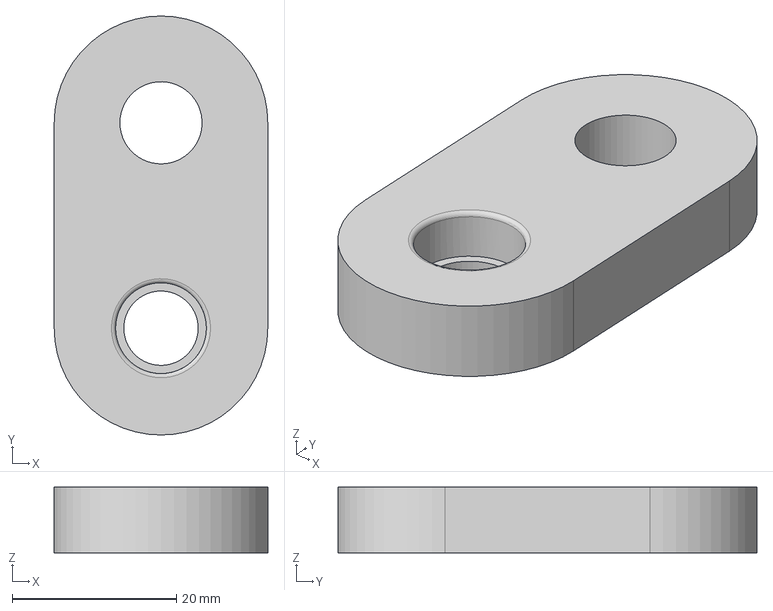
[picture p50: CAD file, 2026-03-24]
step files/Nema 17/6 to 1/CarrierTestHarness.step
26.0 x 51.0 x 8.00 mm

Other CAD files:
step files/Nema 17/6 to 1/SunSpacer.step
AS5600 mount.f3d
CarrierGenerator.f3d
CarrierOutput.f3d
Cover.f3d
GearGenerator.f3d
PlanetModifier.f3d
RingBottom.f3d
RingTop.f3d
SunModifier.f3d
SunSpacer.f3d
lever.f3d

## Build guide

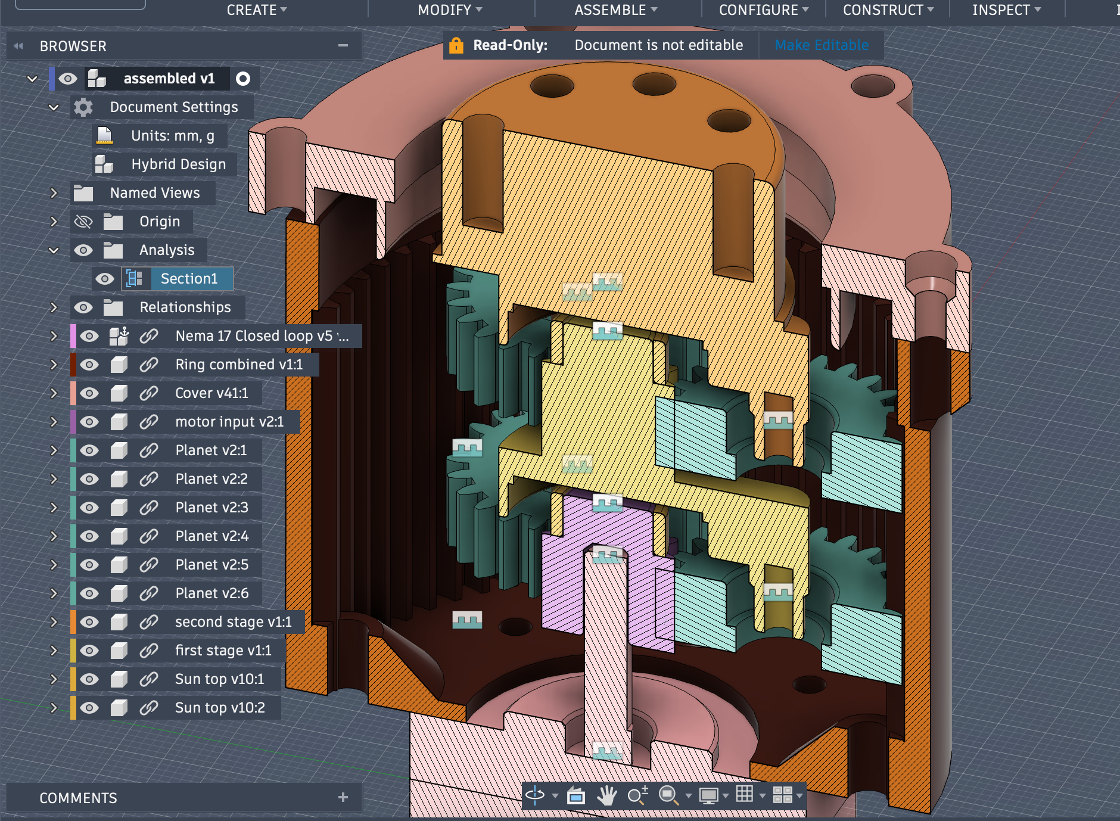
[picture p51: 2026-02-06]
assets/assembled without bearings.png

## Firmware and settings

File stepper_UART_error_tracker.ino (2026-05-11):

#include <AccelStepper.h>

#define RXD2 16
#define TXD2 17

#define STEP_PIN 14
#define DIR_PIN 27

AccelStepper stepper(AccelStepper::DRIVER, STEP_PIN, DIR_PIN);

// --------------------
// MOTOR PARAMETERS
// --------------------

const bool isNema23 = false;

const double FULL_CIRCLE_STEPS =
  isNema23 ? 400.0 : 200.0;

const double FULL_CIRCLE_RADIANS = 6.28318530718;

const double REDUCTION = 36.0;

const int RPM = 30;

const double RADIANS_TO_STEPS =
  FULL_CIRCLE_STEPS / FULL_CIRCLE_RADIANS;

const double STEPS_TO_RADIANS =
  FULL_CIRCLE_RADIANS / FULL_CIRCLE_STEPS;

const double STEPS_PER_SECOND =
  (RPM * FULL_CIRCLE_STEPS) / 60.0;

// --------------------
// SWEEP PARAMETERS
// --------------------

const double SWEEP_ANGLE_RAD = 1.5708;

long targetA;
long targetB;

bool movingToA = false;

// --------------------
// ERROR MONITORING
// --------------------

const byte readErrorCmd[] = { 0xE0, 0x39, 0x19 };

unsigned long lastErrorRequest = 0;
const int requestInterval = 100;

double maxErrorInDegrees = 0;

// --------------------

void setup() {

  Serial.begin(115200);

  Serial2.begin(
    38400,
    SERIAL_8N1,
    RXD2,
    TXD2);

  targetA = 0;

  targetB =
    SWEEP_ANGLE_RAD * REDUCTION * RADIANS_TO_STEPS;

  Serial.print("Target B steps: ");
  Serial.println(targetB);

  Serial.print("Steps/sec: ");
  Serial.println(STEPS_PER_SECOND);

  stepper.setMaxSpeed(STEPS_PER_SECOND);

  stepper.setAcceleration(
    STEPS_PER_SECOND * 2);

  stepper.moveTo(targetB);
}

void loop() {

  // Continuous motion handling
  stepper.run();

  // When target reached, reverse direction
  if (stepper.distanceToGo() == 0) {

    movingToA = !movingToA;

    long target =
      movingToA ? targetA : targetB;


    stepper.moveTo(target);
  }

  // Read angle error periodically
  if (
    millis() - lastErrorRequest
    >= requestInterval) {

    requestMotorError();

    lastErrorRequest = millis();

    Serial.print("Max Error: ");
    Serial.print(maxErrorInDegrees, 4);
    Serial.println(" deg");
  }
}

// =====================================================

void requestMotorError() {

  Serial2.write(readErrorCmd, 3);

  delay(2);

  while (Serial2.available() >= 4) {

    if (Serial2.peek() != 0xE0) {
      Serial2.read();
      continue;
    }

    byte rx[4];

    int n =
      Serial2.readBytes(rx, 4);

    if (n != 4)
      return;

    // Ignore echo packet
    if (
      rx[0] == 0xE0 && rx[1] == 0x39 && rx[2] == 0x19 && rx[3] == 0xE0) {
      continue;
    }

    byte crc =
      (rx[0] + rx[1] + rx[2]) & 0xFF;

    if (crc != rx[3]) {
      continue;
    }

    int16_t raw =
      (rx[1] << 8) | rx[2];

    float angle =
      raw * 360.0 / 65536.0;
    if (abs(angle) > 10) { continue; }
    if (abs(angle) > maxErrorInDegrees) {
      maxErrorInDegrees = abs(angle);
    }
  }
}

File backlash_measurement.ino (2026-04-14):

#include <Adafruit_AS5600.h>

Adafruit_AS5600 as5600;

uint16_t zeroOffset = 0;

void setup() {
  Serial.begin(115200);

  Serial.println("AS5600 Zero Calibration Starting...");

  if (!as5600.begin()) {
    Serial.println("Could not find AS5600 sensor, check wiring!");
    while (1) delay(10);
  }

  // Wait for magnet
  while (!as5600.isMagnetDetected()) {
    Serial.println("Waiting for magnet...");
    delay(200);
  }

  // --- CAPTURE ZERO POSITION ---
  zeroOffset = as5600.getAngle();
  Serial.print("Zero calibrated at raw angle: ");
  Serial.println(zeroOffset);

  Serial.println("AS5600 ready!");

  as5600.enableWatchdog(false);
  as5600.setPowerMode(AS5600_POWER_MODE_NOM);
  as5600.setHysteresis(AS5600_HYSTERESIS_OFF);

  as5600.setOutputStage(AS5600_OUTPUT_STAGE_ANALOG_FULL);

  as5600.setSlowFilter(AS5600_SLOW_FILTER_16X);
  as5600.setFastFilterThresh(AS5600_FAST_FILTER_THRESH_SLOW_ONLY);

  as5600.setZPosition(0);
  as5600.setMPosition(4095);
  as5600.setMaxAngle(4095);
}

void loop() {
  if (!as5600.isMagnetDetected()) {
    Serial.println("No magnet found!");
    delay(200);
    return;
  }
  if (as5600.isAGCminGainOverflow()) {
    Serial.println(" | MH: magnet too strong");
    return;
  }
  if (as5600.isAGCmaxGainOverflow()) {
    Serial.println(" | ML: magnet too weak");
    return;
  }

  uint16_t rawAngle = as5600.getAngle();

  // --- APPLY ZERO OFFSET WITH WRAPAROUND ---
  int32_t corrected = rawAngle - zeroOffset;
  if (corrected < 0) corrected += 4096;

  // Convert to degrees
  float degrees = corrected * 360.0 / 4096.0;

  Serial.print("Degrees: ");
  Serial.print(degrees, 2);
  Serial.print("°");

  Serial.println();

  delay(50);
}

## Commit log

2026-02-06 Added f3d files and Readme
    [Bottom generator.f3d, Carrier generator.f3d, Carrier output generator.f3d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]
2026-02-06 more docs
    [CarrierGenerator.f3d, CarrierOutput.f3d, Cover.step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]
2026-02-06 Update README to include additional parts required for planetary gear assembly
2026-02-06 Fix typo in description of planetary gearbox
2026-02-06 Add print time and filament usage details to README
2026-02-06 Update README and binary files for improved gearbox documentation and assets
    [RingBottom.f3d, SunModifier.f3d]
2026-02-06 Fix grammatical error in README regarding gear assembly instructions
    [PlanetModifier.f3d]
2026-02-06 Fix terminology in README: update 'hex screws' to 'hex bolts' for consistency
2026-02-07 Fix part number for M3 hex bolts in README
    [CarrierGenerator.f3d, Cover.f3d]
2026-02-07 increased sun_width to 13
    [GearGenerator.f3d, SunModifier.f3d]
2026-02-07 Update parts list in README and adjust heat insert quantity
    [CarrierGenerator.f3d, GearGenerator.f3d]
2026-02-07 Add .DS_Store file to step files directory
    [FirstStage.step, MotorInput.step, Planet.step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]
2026-02-08 Update README for clarity and consistency in parts list
    [CarrierGenerator.f3d, CarrierOutput.f3d]
2026-02-12 Add forces_calculator.py for torque and stress calculations in gear system
    [CarrierGenerator.f3d]
2026-02-12 Refactor forces_calculator.py: enhance class structure and improve force calculations for Pin and CarrierArm
2026-02-12 Fix module value and enhance PLA strength definition; update pitch radius calculation in Gear class
2026-02-13 Refactor forces_calculator.py: streamline effective force calculations and update Gear class initialization
2026-02-13 Enhance effective force calculation and improve class structure; add bending stress and bearing checks in Pin and CarrierArm classes
2026-02-13 Implement abstract base class for components and enhance checks in Gear, Pin, CarrierArm, and CarrierHub classes
2026-02-13 Enhance output torque calculation and update CarrierArm initialization; improve FEM load retrieval in display method
2026-02-13 Refactor Pin and CarrierArm classes: rename methods for consistency and improve readability
2026-02-13 Refactor forces calculation and implement stage handling; enhance component initialization and output display
2026-02-13 Enhance display method formatting and add FEM load formatting; update stage display for clarity
2026-02-13 Refactor module constants in forces_calculator.py: unify module representation and update calculations for pitch radius and bending stress
2026-02-13 Refactor face width and diameter variables in forces_calculator.py: unify units to millimeters for consistency
2026-02-13 Enhance stage stress check output: add success messages and improve failure indication for clarity
2026-02-13 Refactor pin calculations in forces_calculator.py: update moment and stress calculations for clarity and accuracy
2026-02-13 Refactor Pin class in forces_calculator.py: enhance shear and moment calculations, add fillet radius parameter, and improve stress concentration factor estimation
2026-02-13 Enhance Pin class: add bolt diameter parameter and improve bending stress calculation to account for combined inertia of pin and bolt
2026-02-14 Refactor forces_calculator.py: rename PLA_STRENGTH to MATERIAL_STRENGTH_MEGA_PASCAL for clarity and consistency; update PIN_FILLET_RADIUS_MM initialization in Pin class
2026-02-14 Refactor forces_calculator.py: remove unused constants and comments; update torque and strength variable names for clarity
2026-02-15 Heat inserts stress calculations
2026-02-15 Refactor forces_calculator.py: update carrier hub dimensions and heat insert depth; introduce MAX_BENDING_FORCE_N for improved calculations
    [CarrierOutput.f3d]
2026-02-17 Refactor forces_calculator.py: update MOTOR_TORQUE_NEWTON_MM to correct value for accurate torque calculations
2026-02-17 using needed force instead of motor input
2026-02-17 Refactor Stage class: streamline torque calculations and component creation for improved clarity and efficiency
2026-02-20 including steel bolt
2026-02-20 Pin class
    No double-counted inertia
    Correct modular ratio bending
    Correct shear redistribution
    Material-specific von Mises
    Proper composite EI for deflection
    Fillet Kt applied only to PLA
2026-02-28 removed bearing stresses
2026-03-01 added von_mises in fem
    [CarrierGenerator.f3d]
2026-03-01 fixed equations for pin to follow UDL cantilever
2026-03-01 pin showing F_t & F_r
2026-03-02 nema x params
    [GearGenerator.f3d, RingBottom.f3d, SunModifier.f3d]
2026-03-07 updated carrier and cover
    [CarrierOutput.f3d, Cover.f3d, gear_ratio_6_lever.step]
2026-03-14 carrier hub fem description
    [Cover.step, FirstStage.step, MotorInput.step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]
2026-03-19 removed MOTOR_EFFICIENCY
2026-03-31 adjust backlash equation for contact ratio:
    [GearGenerator.f3d]
2026-04-14 AS5600 mount
    [AS5600 mount.f3d, AS5600 mount.step]
2026-04-22 increased SUN_FACE_WIDTH_MM to 15 and PLANET_FACE_WIDTH_MM to 10
    [GearGenerator.f3d, PlanetModifier.f3d, SunModifier.f3d]
2026-04-30 backlash to 0.2
    [AS5600 mount.f3d, Cover.f3d, Cover.step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]
2026-05-04 using SupportedPin in first stage
    [CarrierGenerator.f3d]
2026-05-04 made deflection method public
    [RingBottom.f3d]
2026-05-08 nemas radius and chord
    [SunModifier.f3d]
2026-05-08 if(gear_ratio == 6; bearing_4668K225_od; bearing_2349K726_od)
    [PlanetModifier.f3d]
2026-05-08 renamed parameters
    [CarrierGenerator.f3d, CarrierOutput.f3d, Cover.f3d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]
2026-05-10 moved step files to Nema 17 folder
    [AS5600 mount.step, CarrierTestHarness.step, Cover.step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]
2026-05-11 fixed ring_width
    [GearGenerator.f3d]
2026-05-11 Sun Modifier
    [SunModifier.f3d]
2026-05-11 undid SunSpace
    [SunModifier.f3d]
